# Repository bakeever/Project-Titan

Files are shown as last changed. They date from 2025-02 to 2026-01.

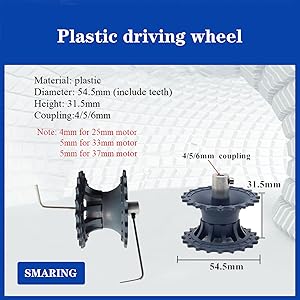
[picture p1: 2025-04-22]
Website/images/drivewheel_spec.jpg

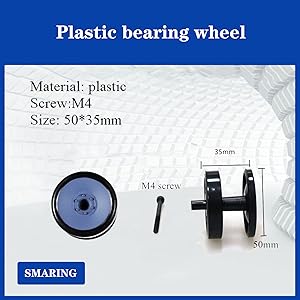
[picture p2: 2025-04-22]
Website/images/bearing_spec.jpg

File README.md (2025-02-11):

# Project TITAN - Configurations Hyperion & Theia

**Developed by Bryce Keever and Benjamin Costello**  
ENGR 385 - Integration 2 | Spring 2025  
Colorado Mesa University  

## Overview

Project TITAN is an advanced autonomous rover designed and developed to demonstrate integrated engineering concepts, including mechatronics, software development, and system integration. This project is part of the ENGR 385 - Integration 2 course at Colorado Mesa University. It serves as a comprehensive exploration of practical engineering applications, combining modern hardware, software, and design methodologies to create a fully functional autonomous system.

Each rover utilizes two Arduino MEGA microcontrollers:
- **Rover Control Unit:** Manages autonomous navigation, sensor integration, and decision-making.
- **Handheld Control Console:** Provides manual control and telemetry monitoring capabilities.

### Features
- **Arduino Programming:** Custom code for sensor input, motor control, and communication protocols.
- **Mechanical Design:** A SolidWorks assembly for the rover chassis and components.
- **Human Interface:** A handheld console for monitoring and operation, including live sensor data visualization.
- **Obstacle Detection:** Utilizes HC-SR04 ultrasonic distance sensors for obstacle detection and avoidance.
- **Precise Movement:** Driven by precision-controlled motors.
- **Control Console:** An intuitive handheld device for manual operation and telemetry feedback.

By leveraging a multidisciplinary approach, Project TITAN demonstrates the practical integration of hardware design, embedded systems, and control strategies, providing a scalable foundation for future autonomous systems research and development.

## Bill of Materials - Hyperion (Tank Rover)
| **Component** | **Description** | **Quantity** |
|---|---|---|
| Arduino MEGA | Microcontroller for the rover brain | 1 |
| Arduino MEGA | Microcontroller for the handheld control console | 1 |
| Wiring Kit | Wiring for connections | Various |
| HC-SR04 Ultrasonic Sensors | Ultrasonic distance sensors for obstacle detection | 3 |
| Motors | Motors for rover movement | TBD |
| Power Supply | 5V DC battery pack | 1 |
| Chassis Components | Mechanical parts for rover structure | TBD |
| Wheels/Tracks | Mobility components | TBD |
| Miscellaneous | Other components and accessories | TBD |

## Bill of Materials - Theia (4x4 Rover)
| **Component** | **Description** | **Quantity** |
|---|---|---|
| Arduino MEGA | Microcontroller for the rover brain | 1 |
| Arduino MEGA | Microcontroller for the handheld control console | 1 |
| Wiring Kit | Wiring for connections | Various |
| HC-SR04 Ultrasonic Sensors | Ultrasonic distance sensors for obstacle detection | 3 |
| Motors | Motors for rover movement | TBD |
| Power Supply | 5V DC battery pack | 1 |
| Chassis Components | Mechanical parts for rover structure | TBD |
| Wheels/Tracks | Mobility components | TBD |
| Miscellaneous | Other components and accessories | TBD |

## Website Link
https://org.coloradomesa.edu/~bakeever/

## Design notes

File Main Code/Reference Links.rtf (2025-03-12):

Website Links:
[Ultrasonic Sensor]
https://macduino.blogspot.com/2013/11/hc-sr04-using-multiple-ultrasonic.html#google_vignetteUBX GPS Arduino Libraryhttps://github.com/loginov-rocks/UbxGpsInstructables: Arduino Ublox GPShttps://www.instructables.com/Arduino-Ublox-GPS/SparkFun_u-blox_GNSS_Arduino_Library:https://github.com/sparkfun/SparkFun_u-blox_GNSS_Arduino_Library/tree/main

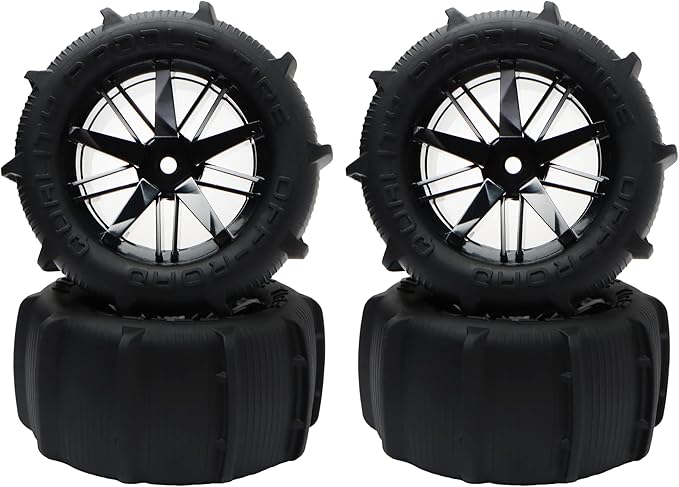
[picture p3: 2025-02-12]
Website/images/concept_rover_wheel_model.jpg

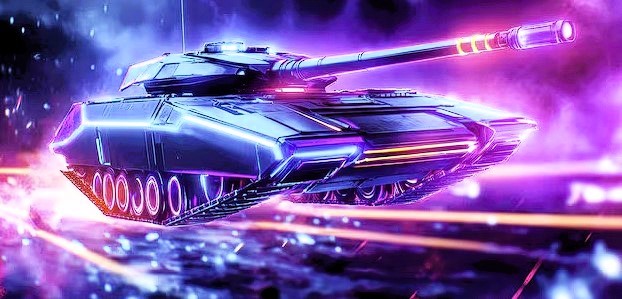
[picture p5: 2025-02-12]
Website/images/concept_drivetrain.jpg

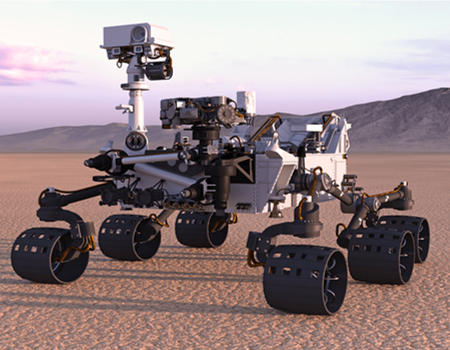
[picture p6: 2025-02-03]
Website/images/concept_rover.png

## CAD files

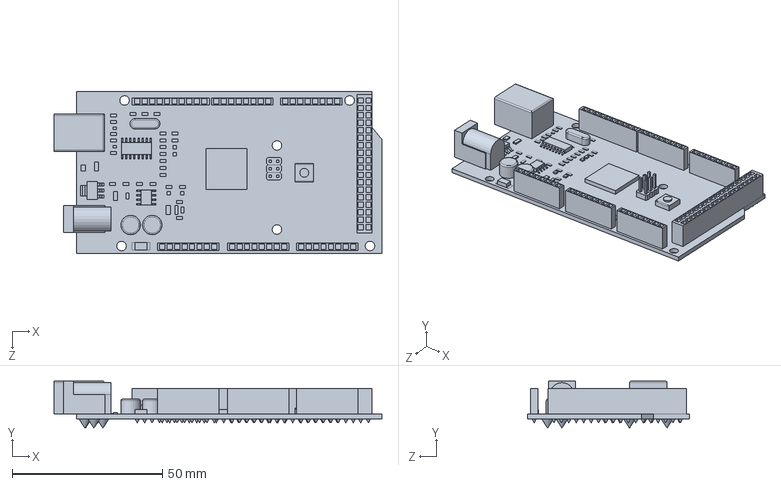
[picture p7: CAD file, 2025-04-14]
CAD/arduino-mega-18.snapshot.5/Arduino_Mega.SLDPRT
109.3 x 15.6 x 54.0 mm

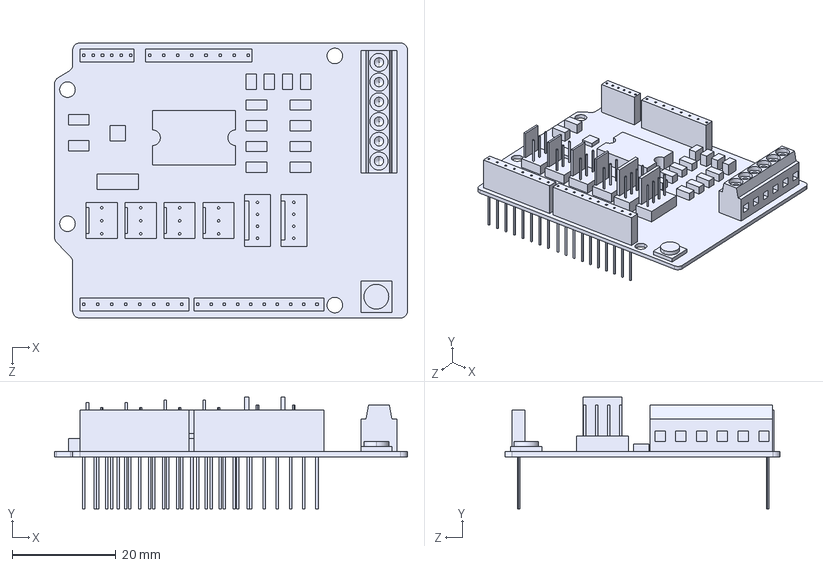
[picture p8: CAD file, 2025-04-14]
CAD/aruino-motor-shield-1.snapshot.2/arduino motor shield.STEP
68.0 x 21.5 x 53.0 mm

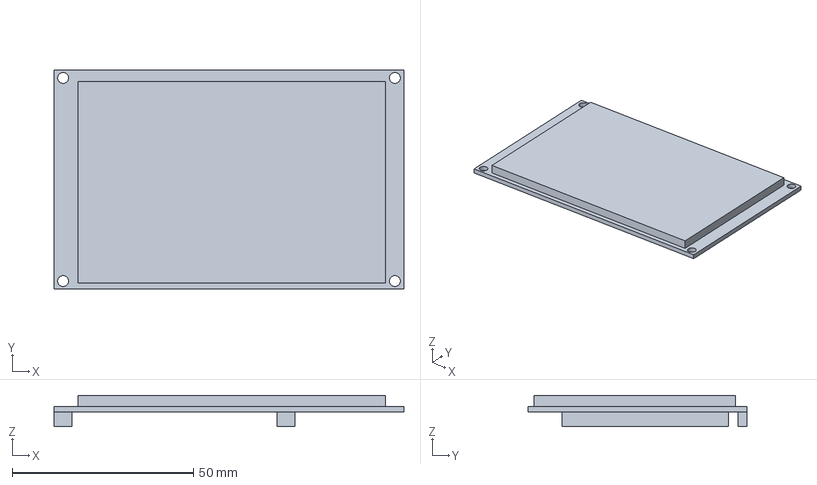
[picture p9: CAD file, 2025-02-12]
CAD/FreeCAD/Console/Screen.FCStd
96.5 x 60.3 x 8.59 mm

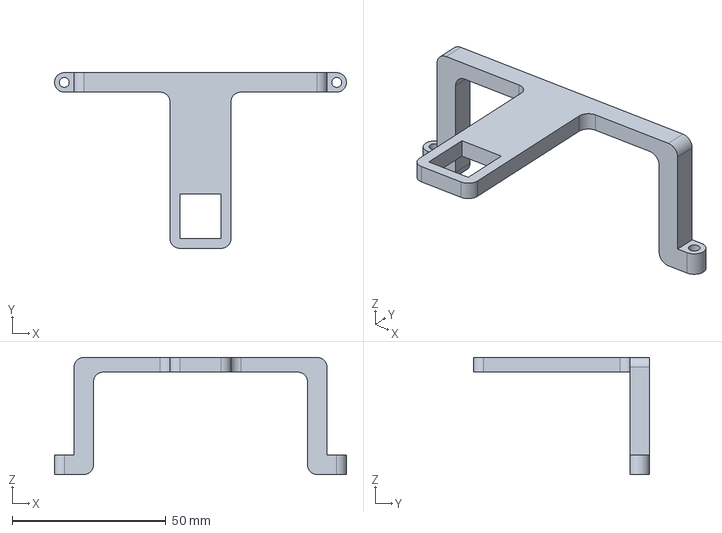
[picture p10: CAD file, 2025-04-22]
CAD/FreeCAD/Magnometer Bracket.FCStd
95.0 x 57.2 x 38.1 mm

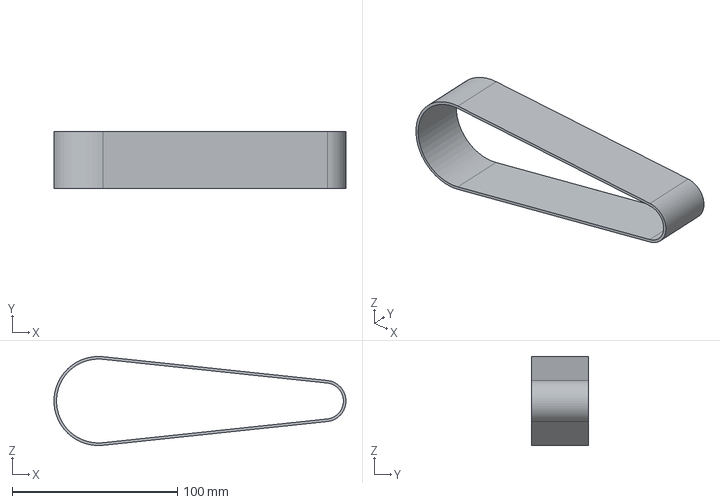
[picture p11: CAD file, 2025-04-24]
CAD/SolidWorks/Freecad Migration/Project Titan_Treadstep.step
176.9 x 34.5 x 54.0 mm

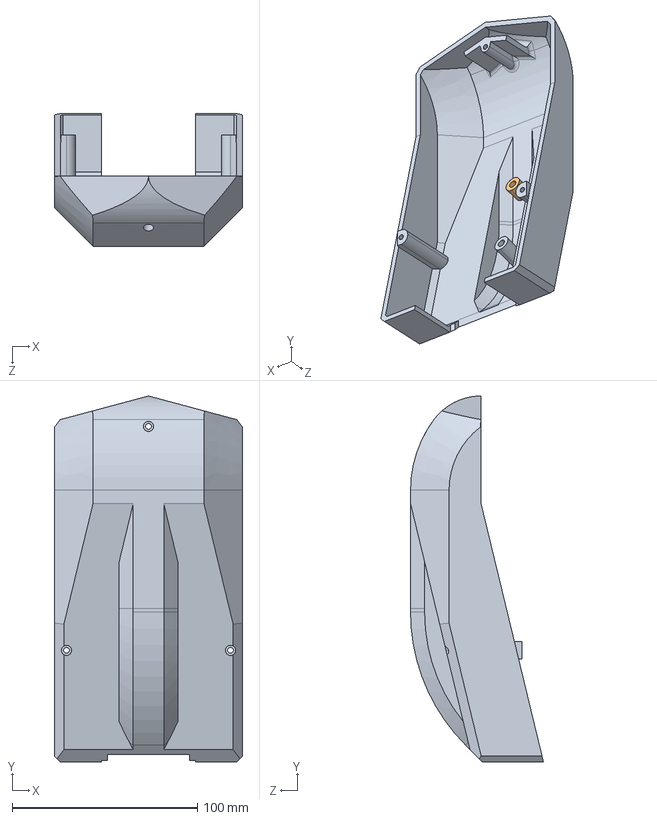
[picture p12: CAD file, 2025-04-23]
CAD/STPs/Project Titan_Chassis_Top.STEP
101.6 x 197.8 x 71.9 mm

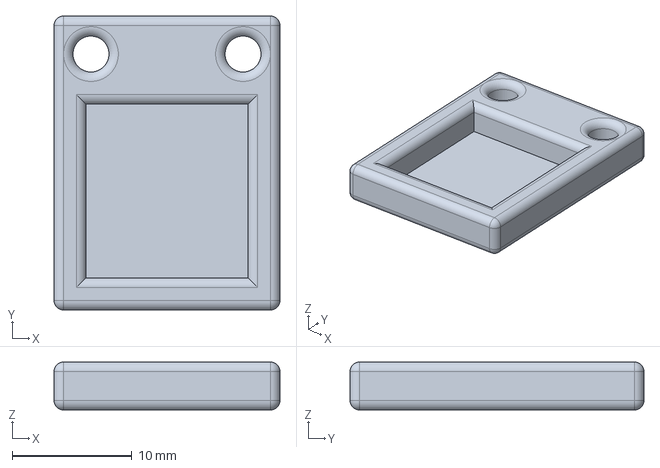
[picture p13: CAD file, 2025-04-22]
CAD/FreeCAD/Cradle_HW-246.FCStd
18.9 x 24.5 x 4.00 mm

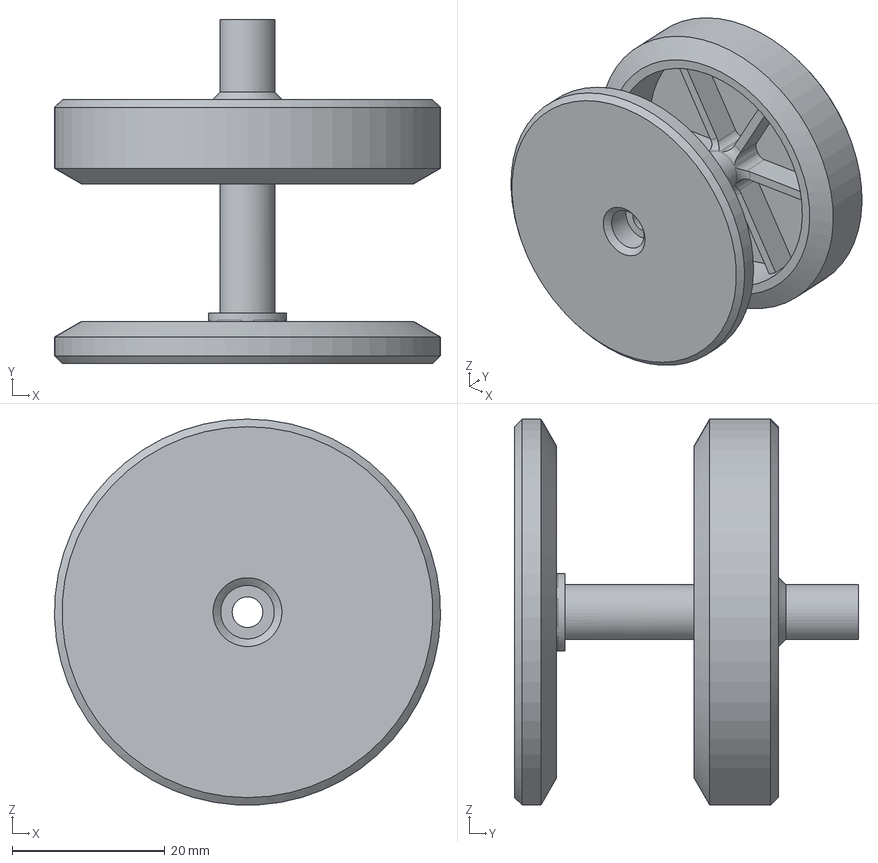
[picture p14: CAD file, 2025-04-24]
CAD/SolidWorks/Freecad Migration/Project Titan_Drive Wheel.step
50.5 x 45.0 x 50.5 mm

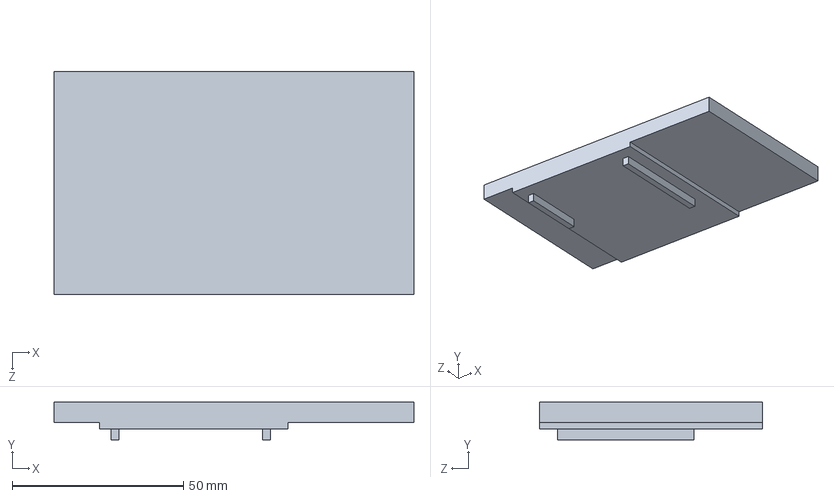
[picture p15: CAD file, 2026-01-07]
Gameduino Screen.SLDPRT
105.0 x 11.0 x 65.0 mm

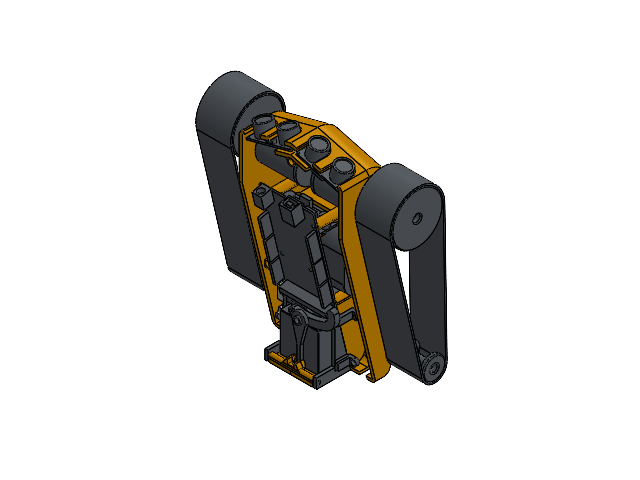
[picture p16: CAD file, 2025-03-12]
Website/downloads/Hyperion_Assembly.SLDASM
Threaded Insert_M3x4mm.step x 12
Lower Chassis.step
Tread Motor.step x 2
Tread.step x 2
Body.step
Body-0.step x 2
Body-1.step
Marker Cube.step
Body-2.step x 2
Wheels_Treads_Idler.step x 2
M3x40mm.step
M4x60mm.step
Tensioner.step
Rail Bracket_01.step x 2
Rail Bracket_01-3.step
Buck Converter.step
Buck Mount.step
Body-4.step
CAM Linkage.step
Tensioner_Rail.step x 2
Gate Linkage.step
Cube Door.step
Door Hinge.step

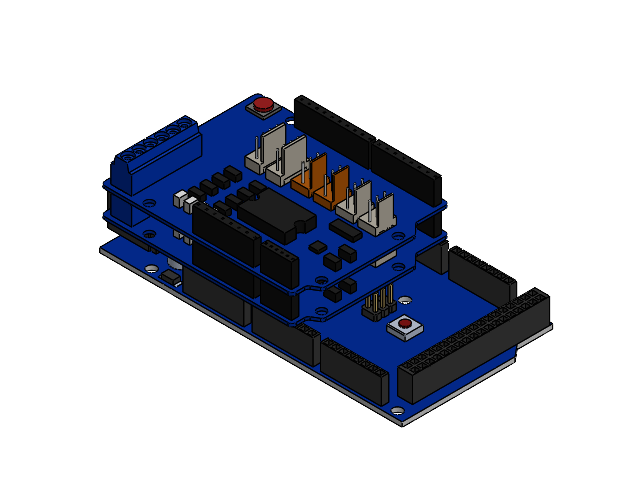
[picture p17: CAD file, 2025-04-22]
CAD/SolidWorks/Freecad Migration/Project Titan_Controller Stack.SLDASM
Arduino_Mega
arduino motor shield x 2

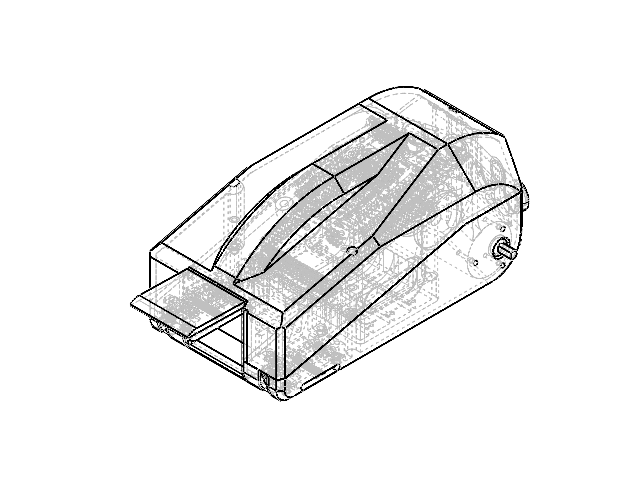
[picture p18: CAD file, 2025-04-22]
CAD/SolidWorks/Freecad Migration/Project Titan_Chassis Lower.SLDASM
Project Titan_Chassis_Base.step
Threaded Insert_M3x4mm.step x 15
Project Titan_Chassis_Compartment.step
Project Titan_Belt Tensioner_End Bracket.step x 4
Project Titan_Belt Tensioner_Linear Rail x 4
Project Titan_Belt Tensioner_Carriage.step x 2
Project Titan_Belt Tensioner_Facade.step x 2
Body.step
Project Titan_Chassis_Door.step
Project Titan_Payload Servo.step
Project Titan_Payload Arm.step
Project Titan_Ultrasonic Sensors x 2
Project Titan_Drivetrain_Motor x 2
Arduino_Mega
arduino motor shield x 2
Project Titan_Chassis_Top

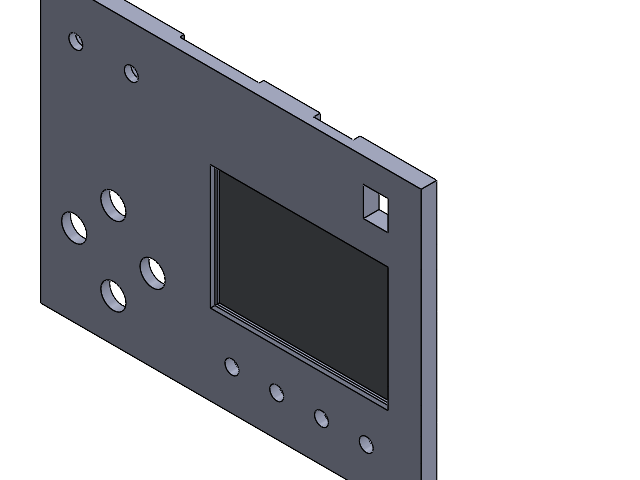
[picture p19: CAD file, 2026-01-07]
Full Assembly.SLDASM
Face Plate - Redesign v.1
Screen-Screen.step

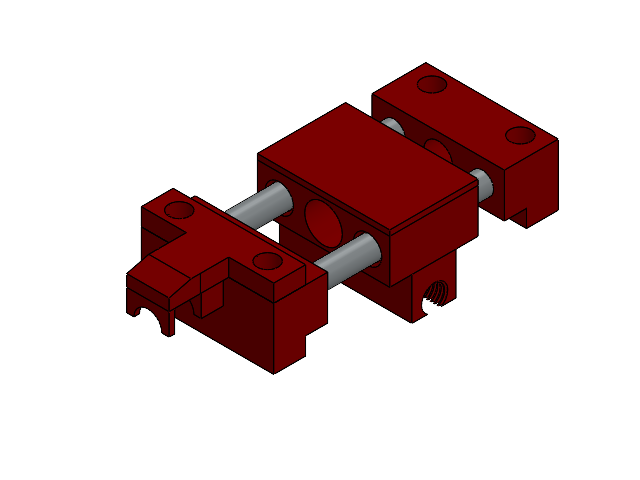
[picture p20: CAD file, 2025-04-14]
CAD/SolidWorks/Freecad Migration/Project TItan_Belt Tensioner_2025-04-14.SLDASM
Project Titan_Belt Tensioner_End Bracket.step x 2
Project Titan_Belt Tensioner_Linear Rail x 2
Project Titan_Belt Tensioner_Carriage.step
Project Titan_Belt Tensioner_Facade.step

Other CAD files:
CAD/FreeCAD/Assembly_Beta_02.FCStd
CAD/FreeCAD/Assembly_Beta_01.FCStd
CAD/FreeCAD/Console/STPs/Screen-Screen.step
CAD/STPs/Magnometer Bracket-Body.step
Arduino_Mega.SLDPRT
CAD/Blender/Draw1.SLDDRW
CAD/FreeCAD/Arduino Mega.FCStd
CAD/FreeCAD/Ball Linkage.FCStd
CAD/FreeCAD/Battery.FCStd
CAD/FreeCAD/Buck Converter.FCStd
CAD/FreeCAD/Buck Mount.FCStd
CAD/FreeCAD/CAM Linkage.FCStd
CAD/FreeCAD/Chassis Base.FCStd
CAD/FreeCAD/Chassis_01.FCStd
CAD/FreeCAD/Chassis_02.FCStd
CAD/FreeCAD/Chassis_03.FCStd
CAD/FreeCAD/Cube Door.FCStd
CAD/FreeCAD/Door Hinge.FCStd
CAD/FreeCAD/Door Hinge_Left.FCStd
CAD/FreeCAD/GPS.FCStd
CAD/FreeCAD/Gate Linkage.FCStd
CAD/FreeCAD/M3x40mm.FCStd
CAD/FreeCAD/M4x60mm.FCStd
CAD/FreeCAD/Marker Cube.FCStd
CAD/FreeCAD/Motor Shield.FCStd
CAD/FreeCAD/Motor_Treads.FCStd
CAD/FreeCAD/Rail Bracket 01.FCStd
CAD/FreeCAD/Rail Bracket 02.FCStd
CAD/FreeCAD/Sensor_ADXL345.FCStd
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

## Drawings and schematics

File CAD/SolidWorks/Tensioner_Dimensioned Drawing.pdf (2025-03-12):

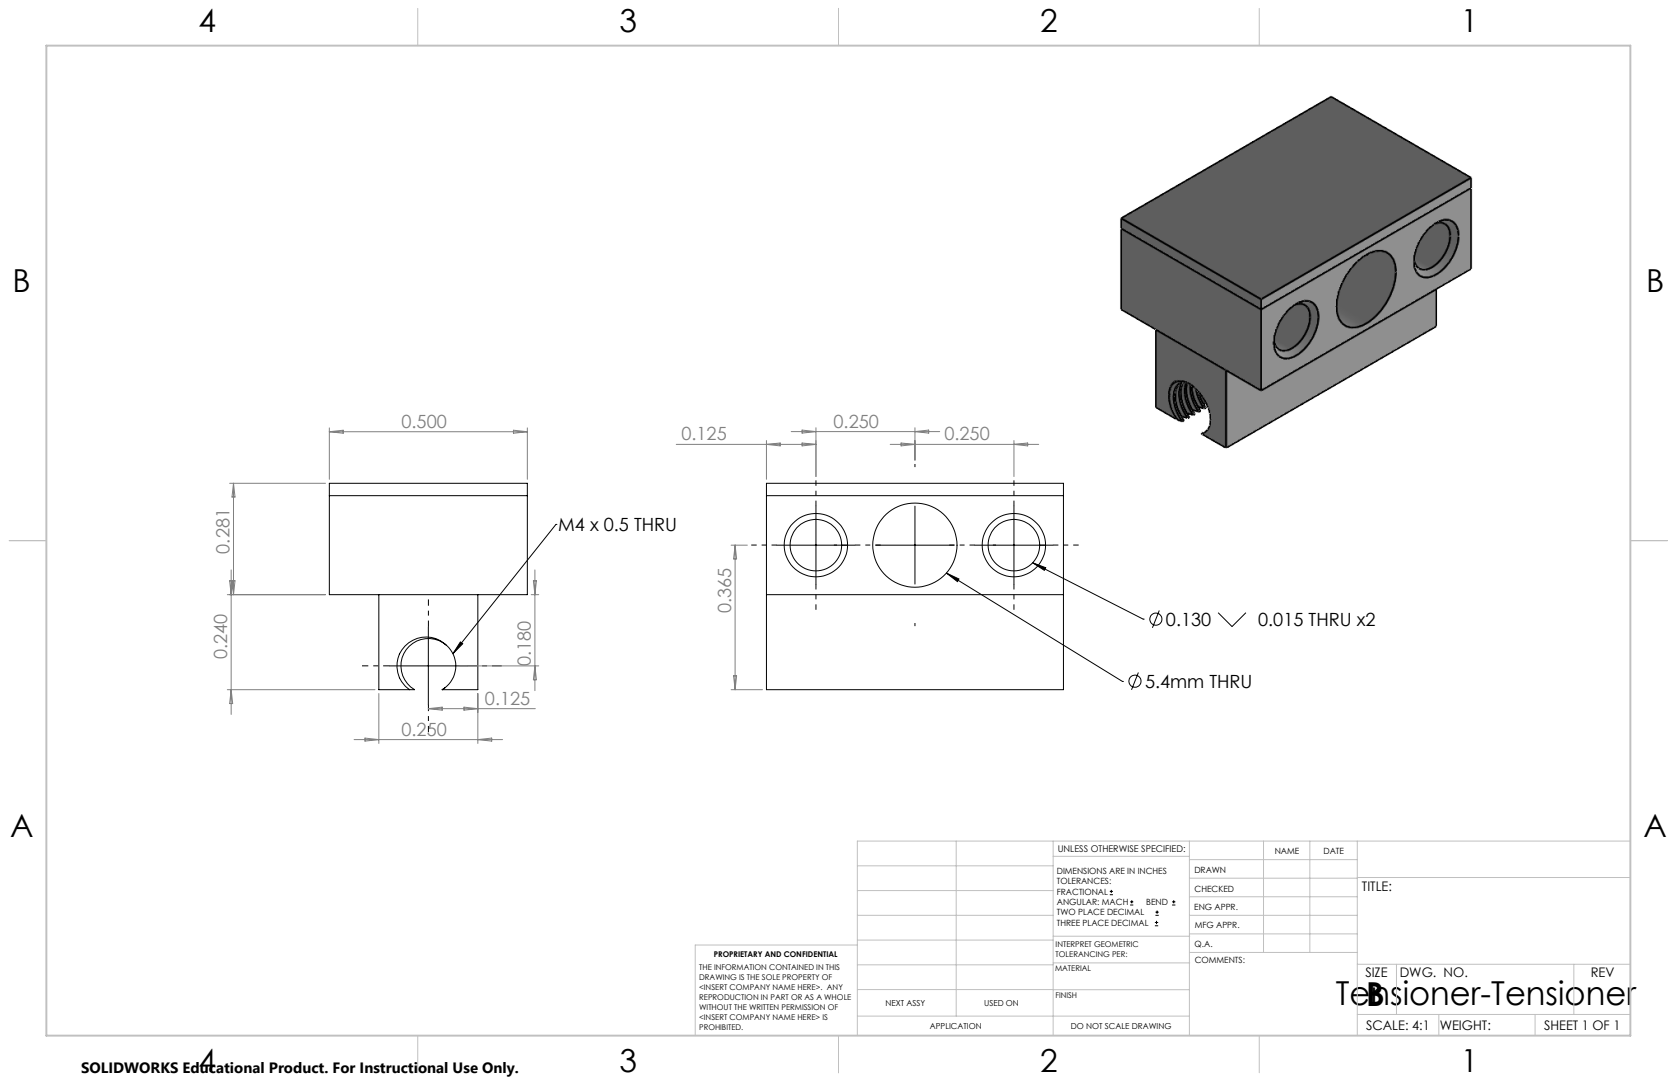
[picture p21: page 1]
M4 x 0.5 THRU; 5.4mm THRU; 0.015 THRU x2

UNLESS OTHERWISE SPECIFIED: | | NAME | DATE
DIMENSIONS ARE IN INCHES TOLERANCES: FRACTIONAL ANGULAR: MACH BEND TWO PLACE DECIMAL THREE PLACE DECIMAL | DRAWN

CHECKED | | | TITLE:

ENG APPR.
MFG APPR.

INTERPRET GEOMETRIC TOLERANCING PER: | Q.A.
MATERIAL | | SIZE B | DWG. NO. | REV

PROPRIETARY AND CONFIDENTIAL
THE INFORMATION CONTAINED IN THIS
DRAWING IS THE SOLE PROPERTY OF
<INSERT COMPANY NAME HERE>. ANY
REPRODUCTION IN PART OR AS A WHOLE
WITHOUT THE WRITTEN PERMISSION OF
<INSERT COMPANY NAME HERE> IS
PROHIBITED.

NEXT ASSY | USED ON | FINISH

APPLICATION | DO NOT SCALE DRAWING | | SCALE: 4:1 | WEIGHT: | SHEET 1 OF 1

SOLIDWORKS Educational Product. For Instructional Use Only.

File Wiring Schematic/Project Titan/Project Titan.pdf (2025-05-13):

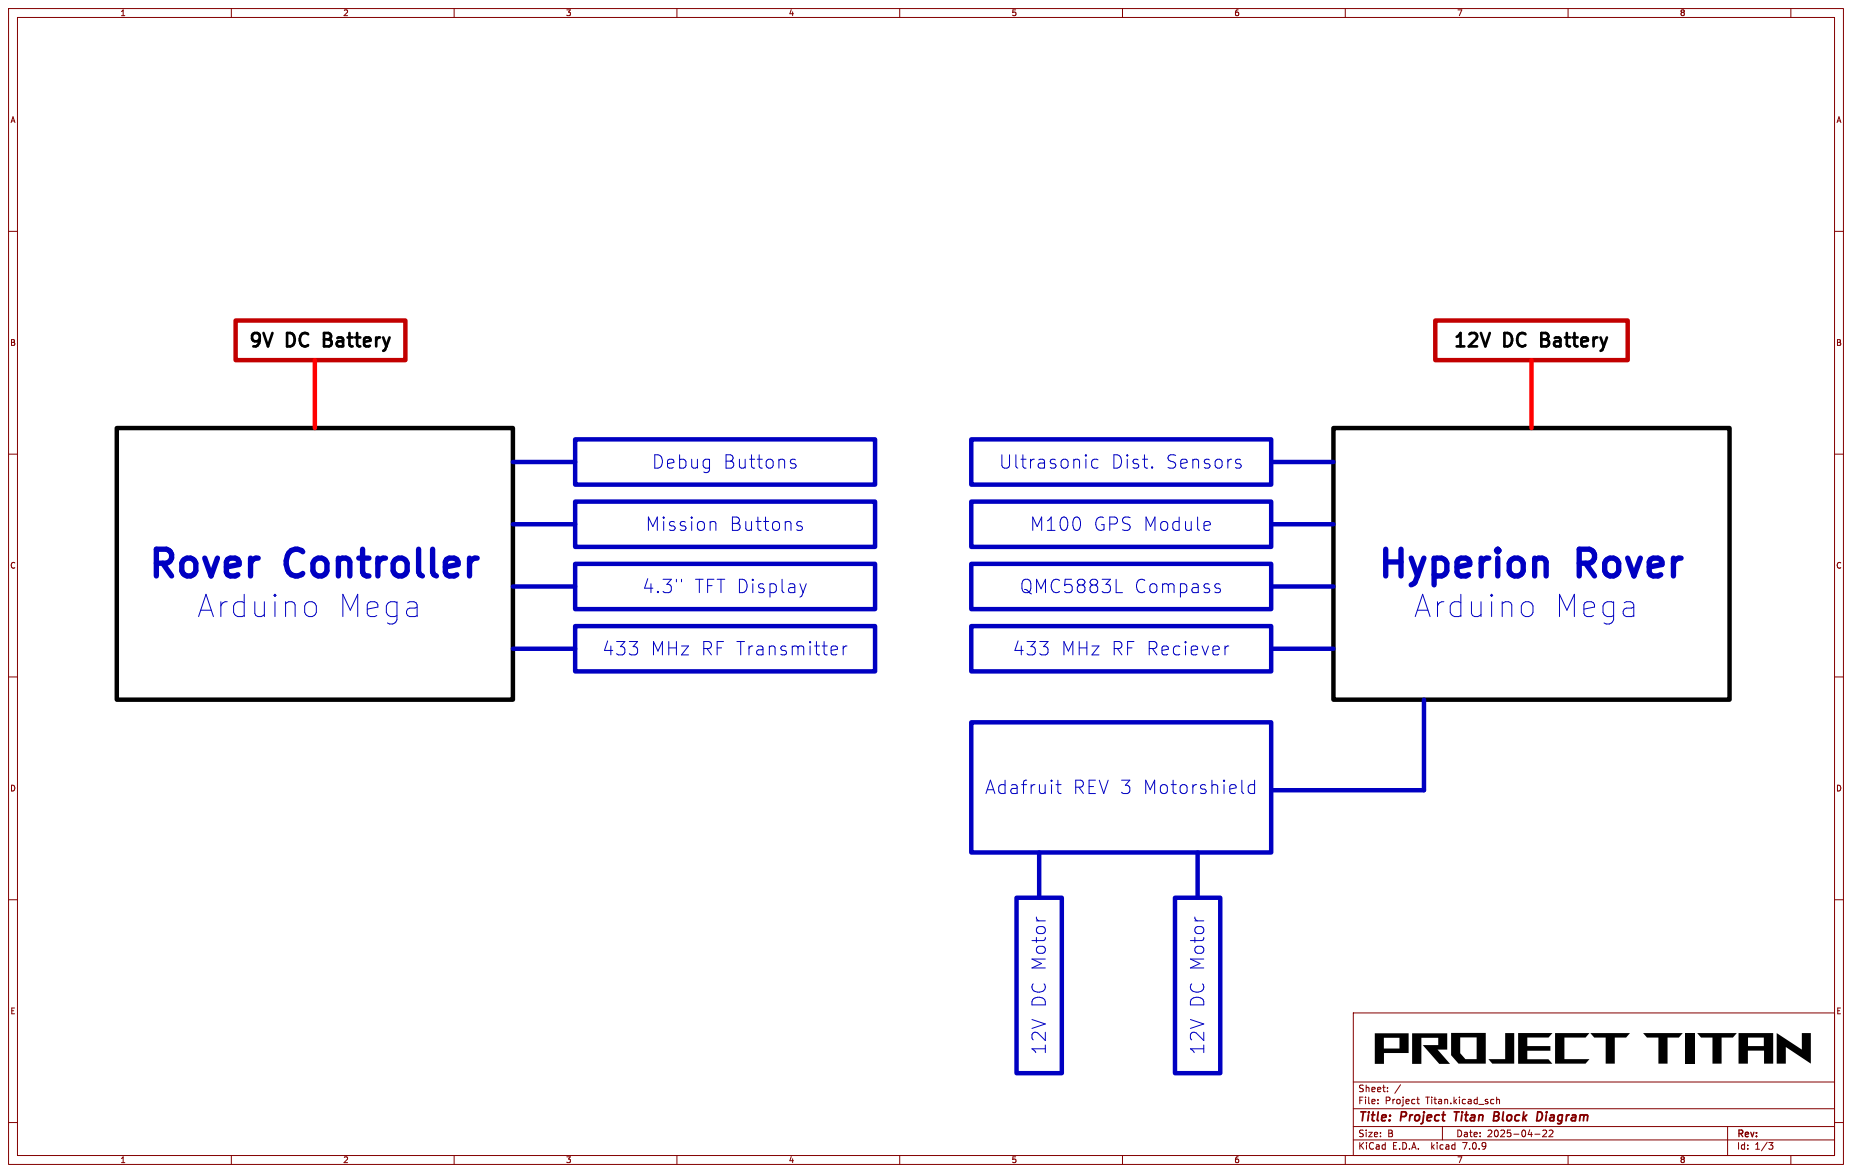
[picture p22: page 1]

Id: 1/3 Title: Project Titan Block Diagram

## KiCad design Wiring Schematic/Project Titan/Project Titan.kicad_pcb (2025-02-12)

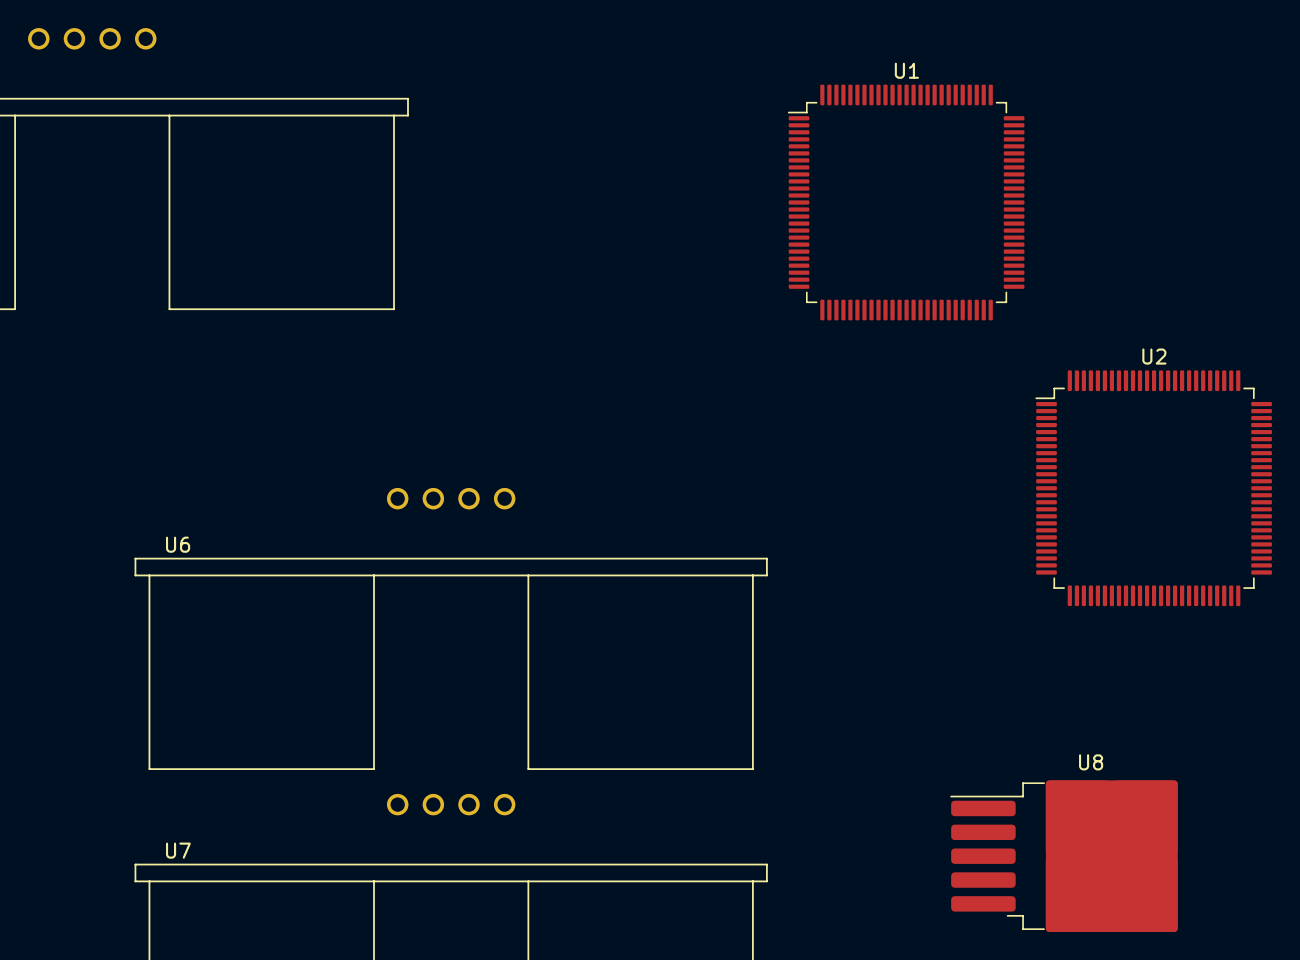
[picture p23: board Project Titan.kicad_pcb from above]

Board: 2 copper layers, 6 parts (0 on the bottom side), 4 nets, no tracks yet.

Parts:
U1, U2: ATmega2560-16A; TQFP-100_14x14mm_P0.5mm
U3, U6, U7: HC-SR04; XCVR_HC-SR04
U8: LM2596S-ADJ; TO-263-5_TabPin3

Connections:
unnamed: U1.11 (GND), U1.32 (GND), U1.62 (GND), U1.81 (GND), U1.99 (GND)
unnamed: U1.10 (VCC), U1.31 (VCC), U1.61 (VCC), U1.80 (VCC)
unnamed: U2.11 (GND), U2.32 (GND), U2.62 (GND), U2.81 (GND), U2.99 (GND)
unnamed: U2.10 (VCC), U2.31 (VCC), U2.61 (VCC), U2.80 (VCC)

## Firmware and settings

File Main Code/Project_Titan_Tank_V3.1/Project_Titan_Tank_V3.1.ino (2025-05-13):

/*
 * ==========================================================
 * Project Name: Project Titan Hyperion
 * Author: Bryce Keever
 * Date: April 9, 2025
 * Version: 3.0
 * Description: Using Arduino Motor Shield Rev3 Clone
 * ==========================================================
 */

// ==========================================================
//                      Library Includes
// ==========================================================
#include <AFMotor.h>
#include <SPI.h>
// Include RadioHead Amplitude Shift Keying Library
#include <RH_ASK.h>
#include <Servo.h>  // Include the Servo library
// I2C Library
#include <Wire.h>
// QMC5883L Compass Library
#include <QMC5883LCompass.h>
#include <TinyGPS++.h>
// ==========================================================
//                      Program Variables
// ==========================================================
// === Serial and GPS Settings ===
#define GPS_SERIAL Serial3
#define GPS_BAUD 38400
#define PC_BAUD 115200

// === Ultrasonic Variables ===
#define NUM_SAMPLES 5  // Number of readings to average
#define PULSE_TIMEOUT 30000  // Timeout for pulseIn() in microseconds
bool sensorsEnabled = true;  // Boolean flag to enable or disable sensors
const long sensorInterval = 1000;  // 1-second interval

unsigned long previousMillis = 0;
const long interval = 3000; // 3 seconds

int pos = 0; // Initial position for servo

uint16_t tread_right = 250; // Initial speed for 
uint16_t tread_left = 250;
uint8_t i; // For accel and deccel
// === RF Messaging ===
static uint8_t buf[10] = {0};  
uint8_t buflen = sizeof(buf);
char currentCommand[10] = "STOP"; // Initial state is STOP
bool turning = false;
int startHeading = 0;
int targetHeading = 0;

// ==========================================================
//                      Pin Declaration
// ==========================================================
/* Ultrasonic Sensor Pins */
#define TRIG_PIN_LEFT 22  // Pin connected to the Trig pin of the sensor
#define ECHO_PIN_LEFT 23 // Pin connected to the Echo pin of the sensor
#define TRIG_PIN_RIGHT 24  // Pin connected to the Trig pin of the sensor
#define ECHO_PIN_RIGHT 25 // Pin connected to the Echo pin of the sensor
#define STARTUP_ERROR 28
#define MAIN_ERROR 29

/* Motor Hat Pins */
const int directionPinR = 12; // Direction Pins
const int directionPinL = 13;

const int pwmPinR = 3; // PWM Pins
const int pwmPinL = 11;

const int brakePinR = 9; // Brake Pins
const int brakePinL = 8;

const bool directionState; //boolean to switch direction (not currently used)

// ==========================================================
//                   Object Declaration
// ========================================================== 

/* Create ASK objects for RF Communication */
RH_ASK rf_driver(2000,19,18,10); // Reciever [Pin 18]
RH_ASK rf_driver1(2000,18,19,10,true); // Transmitter [Pin 19]

/* Servo object */
Servo myServo; 
/* Compass Object */
QMC5883LCompass compass;
/* GPS Object */
TinyGPSPlus gps;
// ==========================================================
//               Program Function Initialization
// ==========================================================



void checkDist(){/* Ultrasonic Sensor Check */
  long duration, dist_mm, distL, distR;

  // Trigger the ultrasonic sensor
  digitalWrite(TRIG_PIN_LEFT, LOW);
  delayMicroseconds(2);
  digitalWrite(TRIG_PIN_LEFT, HIGH);
  delayMicroseconds(10);
  digitalWrite(TRIG_PIN_LEFT, LOW);

  // Measure the echo time
  duration = pulseIn(ECHO_PIN_LEFT, HIGH);

  // Convert time to distance
  distL = (duration * 0.34) / 2;  // Distance in mm

  // Resetting duration variable for reuse
  duration = 0;
  // Trigger the ultrasonic sensor
  digitalWrite(TRIG_PIN_RIGHT, LOW);
  delayMicroseconds(2);
  digitalWrite(TRIG_PIN_RIGHT, HIGH);
  delayMicroseconds(10);
  digitalWrite(TRIG_PIN_RIGHT, LOW);

  distR = (duration * 0.34) / 2;

}
/* 
* Function to return bearing from compass as int.
*/
int getBearing(){
  // Trigger a reading from the compass sensor
  compass.read();

  // Get the raw azimuth value from the compass (0 to 359 degrees)
  int rawBearing = compass.getAzimuth();

  // Apply calibration offset to correct for compass mounting/orientation error
  // Offset = 293° (factory calibration error) + 45° (custom adjustment)
  const int calibrationOffset = 338;
  int adjustedBearing = (rawBearing + calibrationOffset) % 360;
  
  //Adjust for values over 360
  if(adjustedBearing>360){adjustedBearing=adjustedBearing-360;}
  if(adjustedBearing<0){adjustedBearing = adjustedBearing+360;}
  return 360-adjustedBearing;
}
/*
* Function to return measured distance as long int.
*/
long getDistance(int trigPin, int echoPin) {
    long totalDistance, duration, distance;
    int validReadings = 0;

    digitalWrite(trigPin, LOW);
    delayMicroseconds(2);
    digitalWrite(trigPin, HIGH);
    delayMicroseconds(10);
    digitalWrite(trigPin, LOW);

    duration = pulseIn(echoPin, HIGH, PULSE_TIMEOUT);

    distance = (duration * 0.34) / 2;
    return distance;
}
void setDutyRight(int duty){
  analogWrite(pwmPinR,duty);
}
void setDutyLeft(int duty){
  analogWrite(pwmPinL,duty);
}
// Function: Sets Rover Direction Forward
void setDirFor(){
  digitalWrite(directionPinR, HIGH); 
  digitalWrite(directionPinL, LOW);  
}
// Function: Sets Rover Direction backward_debugs
void setDirBack(){
  digitalWrite(directionPinR, LOW); 
  digitalWrite(directionPinL, HIGH);  
}
// Function: Sets Rover Direction Right
void setDirRight(){
  digitalWrite(directionPinR, LOW); 
  digitalWrite(directionPinL, LOW);  
}
// Function: Sets Rover Direction Left
void setDirLeft(){
  digitalWrite(directionPinR, HIGH); 
  digitalWrite(directionPinL, HIGH);  
}

/*
* Function: Sets rover brakes based on passed input (T/F).
*/
void setBrakes(bool state){
  if(state == true){
    //activate brakes
    digitalWrite(brakePinR, HIGH);
    digitalWrite(brakePinL, HIGH);
  }
  else if(state == false){
    //deactivate brakes
    digitalWrite(brakePinR, LOW);
    digitalWrite(brakePinL, LOW);
  }
}
// void accel() {
//   static int i = 0;
//   static unsigned long lastUpdate = 0;

//   if (i < 255 && millis() - lastUpdate > 250) { // Slower acceleration
//     // setDutyRight(i);
//     // setDutyLeft(i);
//     i += 0.1;  // Change to i += 2 for a faster increase
//     lastUpdate = millis();
//   }
// }
// void decel(){
//   static int i = 255;
//   static unsigned long lastUpdate = 0;
  
//   if (i > 0 && millis() - lastUpdate > 5) {
//     // setDutyRight(i);
//     // setDutyLeft(i);
//     i--;
//     lastUpdate = millis();
//   }
// }

/*
* Function to command rover to move forward for hardcoded time delay.
*/
void forward_debug(){
    Serial.print("Forward debug");

    // Set Direction Forward
    digitalWrite(12, LOW); //Establishes forward direction of Channel A
    digitalWrite(13, HIGH);  //Establishes forward direction of Channel B

    // 
    digitalWrite(9, LOW);   //Disengage the Brake for Channel A
    digitalWrite(8, LOW);   //Disengage the Brake for Channel B

    int tread = 255;
    analogWrite(3, tread);   //Spins the motor on Channel A at full speed
    analogWrite(11, tread);    //Spins the motor on Channel B at full speed

    delay(1000);

    digitalWrite(9, HIGH);  //Engage the Brake for Channel A
    digitalWrite(8, HIGH);  //Engage the Brake for Channel B

    analogWrite(3, 0);  
    analogWrite(11, 0);   

}
/*
* Function to command rover to move forward for given time delay.
* Also includes straight line adjustment based on heading value.
*/
void forward(int wait){
    int ForwardHeading = getBearing();
    int startTime = millis();
    Serial.print("Forward debug");
    // Set Direction Forward
    digitalWrite(12, HIGH); //Establishes forward direction of Channel A
    digitalWrite(13, LOW);  //Establishes backward_debug direction of Channel B

    // Disengagese Brakes
    digitalWrite(9, LOW);   //Disengage the Brake for Channel A
    digitalWrite(8, LOW);   //Disengage the Brake for Channel B
  
    analogWrite(3, 255);   //Spins the motor on Channel A at full speed
    analogWrite(11, 255);    //Spins the motor on Channel B at half speed

    if (getBearing() < ForwardHeading){
        tread_right = tread_right - 5;
        // setDutyRight(tread_right);
        analogWrite(3, tread_right);   // Changes the speed of Channel A
        tread_left = tread_left +5;
        // setDutyLeft(tread_left);
        analogWrite(11, tread_left);    // Changes the speed of Channel B
    }
    else if (getBearing() > ForwardHeading){
        tread_right = tread_right + 5;
        // setDutyRight(tread_right);
        analogWrite(3, tread_right);   // Changes the speed of Channel A
        tread_left = tread_left - 5;
        // setDutyLeft(tread_left);
        analogWrite(11, tread_left);    // Changes the speed of Channel B
    }
    if (millis() > startTime + wait){
      digitalWrite(9, HIGH);  //Engage the Brake for Channel A
      digitalWrite(8, HIGH);  //Engage the Brake for Channel B
    }
}
/*
* Function to command rover to move forward for given delay time and num of loops.
*/
void forward(int wait, int loops){
  /*
    New version of "forward" function, modifying by controlling each motor 
    on sinusodal pattern to cause the rover to drive in a wobbly
    fashion, thus increasing the chance of seeing a wall before 
    running into it.
  */
  int i = 0; // Variable for number of loops
  float angle = 0; //this angle is in RADIANS
  // setDirFor();
  // setBrakes(false); //release breaks
  // setDutyRight(255);
  // setDutyLeft(255);

  // Set Direction Forward
  digitalWrite(12, HIGH); //Establishes forward direction of Channel A
  digitalWrite(13, LOW);  //Establishes backward_debug direction of Channel B
  // Disengagese Brakes
  digitalWrite(9, LOW);   //Disengage the Brake for Channel A
  digitalWrite(8, LOW);   //Disengage the Brake for Channel B

  while (i<loops){
    float tread_right = (sin(angle+3.14159)+1)*255;
    float tread_left = (sin(angle)+1)*255;
    Serial.print("Forward debug");
    // setDutyRight(tread_right);
    // setDutyLeft(tread_left);
    analogWrite(3, tread_right);   // Changes the speed of Channel A
    analogWrite(11, tread_left);    // Changes the speed of Channel B
    delay(wait);

    angle = angle + 3.14159;
    i++;
  }
  //activate breaks
  // setBrakes(true);
  // //set work duty for the motor to 0 (off)
  // setDutyRight(0);
  // setDutyLeft(0);
  digitalWrite(9, HIGH);  //Engage the Brake for Channel A
  digitalWrite(8, HIGH);  //Engage the Brake for Channel B
}
/*
* Mission Function: Move rover forward.
*/
void Forward(){
    // Set Direction Forward
    digitalWrite(12, LOW); //Establishes forward direction of Channel A
    digitalWrite(13, HIGH);  //Establishes forward direction of Channel B

    // 
    digitalWrite(9, LOW);   //Disengage the Brake for Channel A
    digitalWrite(8, LOW);   //Disengage the Brake for Channel B

    int tread = 255;
    analogWrite(3, tread);   //Spins the motor on Channel A at full speed
    analogWrite(11, tread);    //Spins the motor on Channel B at full speed
    delay(1000);
}
/*
* Function to command rover to move backward for hardcoded time delay.
*/
void backward_debug(){
    Serial.print("backward debug");

    // Set Direction Forward
    digitalWrite(12, HIGH); //Establishes forward direction of Channel A
    digitalWrite(13, LOW);  //Establishes forward direction of Channel B

    // 
    digitalWrite(9, LOW);   //Disengage the Brake for Channel A
    digitalWrite(8, LOW);   //Disengage the Brake for Channel B

    int tread = 255;
    analogWrite(3, tread);   //Spins the motor on Channel A at full speed
    analogWrite(11, tread);    //Spins the motor on Channel B at full speed

    delay(1000);

    digitalWrite(9, HIGH);  //Engage the Brake for Channel A
    digitalWrite(8, HIGH);  //Engage the Brake for Channel B

    analogWrite(3, 0);  
    analogWrite(11, 0);  
}
/*
* Mission Function: Move rover backward.
*/
void Backward(){

}
/*
* Function to command rover to turn to the right 90 degrees.
*/
void right(){
    Serial.println("RIGHT TURN");
      //Motor A forward @ full speed
    digitalWrite(12, LOW); //Establishes forward direction of Channel A
    digitalWrite(9, LOW);   //Disengage the Brake for Channel A
    analogWrite(3, 255);   //Spins the motor on Channel A at full speed

    //Motor B backward_debug @ half speed
    digitalWrite(13, LOW);  //Establishes backward_debug direction of Channel B
    digitalWrite(8, LOW);   //Disengage the Brake for Channel B
    analogWrite(11, 255);    //Spins the motor on Channel B at half speed

    delay(150);

    digitalWrite(9, HIGH);  //Engage the Brake for Channel A
    digitalWrite(8, HIGH);  //Engage the Brake for Channel B

    analogWrite(3, 0);  
    analogWrite(11, 0);  
    // setDirRight();        // Set motors to turn right (left motor forward, right motor backward_debug)
    // setBrakes(false);     // Release brakes
    // setDutyRight(200);    // Power for right motor (backward_debug)
    // setDutyLeft(200);     // Power for left motor (forward)
    // delay(300);           // Duration of the turn
    // setBrakes(true);      // Apply brakes
    // setDutyRight(0);      // Stop motors
    // setDutyLeft(0);
}
/*
* Function to command rover to turn to the right 90 degrees.
* Includes heading value to turn right with increaed accuracy.
*/
void right3(){
    Serial.println("RIGHT TURN");

    int ForwardHeading = getBearing(); // Store the current heading
    digitalWrite(12, LOW); //Establishes forward direction of Channel A
    digitalWrite(13, LOW);
  

    // Set Duty of both motors
    analogWrite(3, 255);  
    analogWrite(11, 255);    
    // Turn until heading is approx. 90° less than starting heading
    while (getBearing() > ForwardHeading - 90){
        Serial.print("turning");
        delay(5);
    }
    digitalWrite(9, HIGH);  //Engage the Brake for Channel A
    digitalWrite(8, HIGH);  //Engage the Brake for Channel B

    setDutyRight(0);
    setDutyLeft(0);
}
/*
* Function to command rover to turn to the left 90 degrees.
*/
void left(){
    Serial.println("LEFT TURN");
    //Motor A forward @ full speed
    digitalWrite(12, HIGH); //Establishes forward direction of Channel A
    digitalWrite(9, LOW);   //Disengage the Brake for Channel A
    analogWrite(3, 255);   //Spins the motor on Channel A at full speed

    //Motor B backward_debug @ half speed
    digitalWrite(13, HIGH);  //Establishes backward_debug direction of Channel B
    digitalWrite(8, LOW);   //Disengage the Brake for Channel B
    analogWrite(11, 255);    //Spins the motor on Channel B at half speed

    delay(150);

    digitalWrite(9, HIGH);  //Engage the Brake for Channel A
    digitalWrite(8, HIGH);  //Engage the Brake for Channel B

    analogWrite(3, 0);  
    analogWrite(11, 0);  
    // setDirLeft();         // Set motors to turn left (right motor forward, left motor backward_debug)
    // setBrakes(false);     // Release brakes
    // setDutyRight(200);    // Power for right motor (forward)
    // setDutyLeft(200);     // Power for left motor (backward_debug)
    // delay(300);           // Duration of the turn
    // setBrakes(true);      // Apply brakes
    // setDutyRight(0);      // Stop motors
    // setDutyLeft(0);
}
/*
* Function: Left turn until rover has rotated approximately 90 degrees.
* Includes heading value to turn right with increaed accuracy.
*/
void left3(){
    Serial.println("LEFT TURN");

    int ForwardHeading = getBearing(); // Store the current heading
    setDirLeft();                      // Set motors for left turn (right forward, left backward_debug)
    setBrakes(false);                 // Release brakes

    setDutyRight(200);                // Power both motors
    setDutyLeft(200);

    // Turn until heading
    while (getBearing() < ForwardHeading + 90){
        Serial.print("turning");
        delay(5);
    }
    setBrakes(true);                 // Stop the rover
    setDutyRight(0);
    setDutyLeft(0);
}
/*
* Payload Function: Moves swing arm with servo to ejecto the payload.
*/
void payload(){
  int pos = 0;    // variable to store the servo position
  for (pos = 180; pos >= 0; pos -= 1) { // goes from 180 degrees to 0 degrees
    myServo.write(pos);              // tell servo to go to position in variable 'pos'
    delay(2);                       // waits 15ms for the servo to reach the position
  }
    for (pos = 0; pos <= 180; pos += 1) { // goes from 0 degrees to 180 degrees in steps of 1 degree
    myServo.write(pos);              // tell servo to go to position in variable 'pos'
    delay(5);                       // waits 15ms for the servo to reach the position
  }
}
/*
* Function to return distance. Used in previous missions to calculate distance per time.
*/
void travelDistance(int distance){
  // Given that 10 feet takes 4000ms, calculate delay as 400ms per foot - changed to 4.77/ft
  int delayTime = distance * 380;
  Serial.print("Traveling ");
  Serial.print(distance);
  Serial.print(" feet (");
  Serial.print(delayTime);
  Serial.println(" ms).");
  forward(delayTime);
  delay(1000);
  payload();
  delay(500);
  forward(500);
}
/*
* Handshake Function: Verifies RF communication is working.
*/
bool handshakeRF(){
  if (rf_driver.recv(buf, &buflen)) {
    buf[buflen] = '\0';  // Null-terminate the received message
    Serial.print("Received: ");
    Serial.println((char*)buf);

    // If handshake message received, respond with "ACK"
    if (strcmp((char*)buf, "HANDSHAKE") == 0) {
        Serial.println("Sending ACK...");
        char ackMsg[] = "ACK";
        rf_driver1.send((uint8_t *)ackMsg, strlen(ackMsg));
        rf_driver1.waitPacketSent();
        return true;
    }
  }
}
/* 
* Handshake function: Verifies functionality of both motors, direction setting and brakes. 
*/
bool handshakeMotor(){
  // Set Direction Forward
  digitalWrite(12, HIGH); //Establishes forward direction of Channel A
  digitalWrite(13, LOW);  //Establishes backward_debug direction of Channel B
  //release breaks
  digitalWrite(brakePinR, LOW);
  digitalWrite(brakePinL, LOW);
  //set work duty for the motor
  analogWrite(pwmPinR, 255);
  analogWrite(pwmPinL, 255);
  delay(500);
  //activate breaks
  digitalWrite(brakePinR, HIGH);
  digitalWrite(brakePinL, HIGH);
  // Set Direction backward_debug
  digitalWrite(12, HIGH); //Establishes forward direction of Channel A
  digitalWrite(13, LOW);  //Establishes backward_debug direction of Channel B
  //set work duty for the motor
  analogWrite(pwmPinR, 255);
  analogWrite(pwmPinL, 255);
  delay(500);
  //activate breaks
  digitalWrite(brakePinR, HIGH);
  digitalWrite(brakePinL, HIGH);
  //set work duty for the motor to 0 (off)
  analogWrite(pwmPinR, 0);
  analogWrite(pwmPinL, 0);
  delay(1000);
  return true;
}
/* 
* Handshake function: Verifies functionality of GPS and GPS-Compass.
*/

/* 
* Handshake function: Verifies functionality of both Ultrasonic distance sensors.
*/
bool handshakeUltra(){
  long duration, distL, distR;

  // Trigger the ultrasonic sensor
  digitalWrite(TRIG_PIN_LEFT, LOW);
  delayMicroseconds(2);
  digitalWrite(TRIG_PIN_LEFT, HIGH);
  delayMicroseconds(10);
  digitalWrite(TRIG_PIN_LEFT, LOW);

  // Measure the echo time
  duration = pulseIn(ECHO_PIN_LEFT, HIGH);

  // Added delay for reading accuracy
  delay(100);
  
  // Convert time to distance
  distL = (duration * 0.34) / 2;  // Distance in mm
  // Trigger the ultrasonic sensor
  digitalWrite(TRIG_PIN_RIGHT, LOW);
  delayMicroseconds(2);
  digitalWrite(TRIG_PIN_RIGHT, HIGH);
  delayMicroseconds(10);
  digitalWrite(TRIG_PIN_RIGHT, LOW);
  // Measure the echo time
  duration = pulseIn(ECHO_PIN_RIGHT, HIGH);
  distR = (duration * 0.343) / 2;
  Serial.print("Distance Left:"); Serial.println(distL);
  Serial.print("Distance Right:"); Serial.println(distR);
  return true;
}
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
void loop() {
  if (rf_driver.recv(buf, &buflen)) {
      buf[buflen] = '\0';  // Null-terminate the received message
      Serial.print("Received: ");
      Serial.println((char*)buf);
      // Process movement commands
      parseCommand((char*)buf);
      Serial.print("Waiting for next command");
      memset(buf, 0, sizeof(buf));
      delay(50);  // Small delay to prevent CPU overload
  }
  // Continuously execute movement based on latest command
  executeMovement();
}

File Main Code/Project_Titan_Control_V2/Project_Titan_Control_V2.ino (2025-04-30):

/*
 * ==========================================================
 * Project Name: Project Titan Control Center
 * Author: Bryce Keever
 * Date: January 27, 2025
 * Version: 2.0 - Modular Mission Handler
 * Description: Modular mission logic using TFT_HX8357 and RH_ASK
 * ==========================================================
 */

// ==========================================================
//                      Library Includes
// ==========================================================
#include <TFT_HX8357.h>
#include <SPI.h>
#include <RH_ASK.h>

// ==========================================================
//                      Object Declaration
// ==========================================================
TFT_HX8357 tft = TFT_HX8357();
RH_ASK rf_driver(2000, 19, 18, 10);  // TX on D18, RX on D18
bool wasManualAdjustActive = false;
int activeManualAdjust = -1; // Index in missions[], or -1 if none active
// ==========================================================
//                      Mission Struct
// ==========================================================
struct Mission {
  int pin;
  bool state;
  int prevState;
  const char* name;
  const char* onMessage;
  const char* offMessage;
  bool isManualAdjust;
  int potIndex;
};


// ==========================================================
//                      Mission Array
// ==========================================================
Mission missions[] = {
  {11, false, HIGH, "Mission 1A", "Scouting Perimeter", "Stop Mission 1A", false, -1},
  {10, false, HIGH, "Mission 1B", "Kamikaze Assignment", "Stop Mission 1B", false, -1},
  {9,  false, HIGH, "Mission 2A", "Analyzing Minerals", "Stop Mission 2A", false, -1},
  {8,  false, HIGH, "Mission 4A",  "I'm going on an adventure!", "Stop Mission 3", false, -1},

  {14, false, HIGH, "Adjust1", "Manual Adjust 1 Enabled", "Manual Adjust 1 Disabled", true, 0},
  {15, false, HIGH, "Adjust2", "Manual Adjust 2 Enabled", "Manual Adjust 2 Disabled", true, 1},
  {A9, false, HIGH, "Adjust3", "Manual Adjust 3 Enabled", "Manual Adjust 3 Disabled", true, 2},
  {A8, false, HIGH, "Adjust4", "Manual Adjust 4 Enabled", "Manual Adjust 4 Disabled", true, 3}
};




const int NUM_MISSIONS = sizeof(missions) / sizeof(missions[0]);

// ==========================================================
//                      Pin Declaration
// ==========================================================
const int button7 = 7;  // Move Backward
const int button6 = 6;  // Move Left
const int button5 = 5;  // Move Right
const int button4 = 4;  // Move Forward
const int button3 = 3;  // E-STOP

// Manual Adjustment Buttons
const int button14 = 14;  // Set Manual Adjust 1
const int button15 = 15;  // Set Manual Adjust 2

const int potPin_1 = A0;
const int potPin_2 = A1;
const int potPin_3 = A2;
const int potPin_4 = A3;
// ==========================================================
//                      Variables
// ==========================================================
String activeMission = "None";
String missionData = "Awaiting Data";

// ==========================================================
//                      Setup
// ==========================================================
void setup() {
  Serial.begin(115200);
  tft.begin();
  tft.setRotation(1);

  if (!rf_driver.init()) {
    Serial.println("RF Module Initialization Failed!");
  } else {
    Serial.println("RF Module Initialized.");
  }

  // E-STOP
  pinMode(button3, INPUT_PULLUP);
  attachInterrupt(digitalPinToInterrupt(button3), toggleLoop, FALLING);

  splash();

  // Button Pins
  for (int i = 4; i <= 11; i++) {
    pinMode(i, INPUT_PULLUP);
  }
  for (int i = 14; i <= 17; i++) {
    pinMode(i, INPUT_PULLUP);
  }
    for (int i = A4; i <= A9; i++) {
    pinMode(i, INPUT_PULLUP);
  }
}


// ==========================================================
//                      Splash Screen
// ==========================================================
void splash() {
  tft.fillScreen(TFT_BLACK);
  tft.setTextColor(TFT_WHITE, TFT_BLACK);
  tft.setTextSize(3);
  int16_t x = 65;  // original centering
  tft.setCursor(x, 140);
  tft.print("Project Titan");
  tft.setTextSize(2);
  tft.setCursor(x, 170);  // 30 pixels below
  tft.print("Tiny Frame. Boundless Vision.");
  delay(3000);

  tft.fillScreen(TFT_BLACK);
  tft.setTextSize(2);
  tft.setCursor((480 - (25 * 2 * 7)) / 2, 10); // Centered title
  tft.print("Project Titan Control Center");

  int boxX = 10, boxY = 70, boxWidth = 460, boxHeight = 240;
  tft.drawRect(boxX, boxY, boxWidth, boxHeight, TFT_WHITE);
  tft.setCursor(boxX + 10, boxY + 10);
  tft.print("Mission Data:");
  tft.setCursor(boxX + 10, boxY + 30);
  tft.print(missionData);
}

// ==========================================================
//                      Mission Display
// ==========================================================
void updateActiveMission(String mission) {
  if (mission != activeMission) {
    activeMission = mission;
    String activeMissionText = "Active Mission: " + activeMission;
    int16_t mission_width = activeMissionText.length() * 12; // Assume 12px/char
    int16_t mission_x_center = (480 - mission_width) / 2;

    tft.setTextSize(2);
    tft.setTextColor(TFT_WHITE, TFT_BLACK);
    tft.fillRect(0, 35, 480, 24, TFT_BLACK); // clear line at y=35
    tft.setCursor(mission_x_center, 35);
    tft.print(activeMissionText);
  }
}


void updateMissionData(String data) {
  if (data != missionData) {
    missionData = data;
    tft.setTextSize(2);
    tft.setTextColor(TFT_WHITE, TFT_BLACK);
    tft.fillRect(20, 100, 440, 200, TFT_BLACK);
    tft.setCursor(20, 100);
    tft.print(missionData);
  }
}


// ==========================================================
//                      Mission Handling
// ==========================================================
void handleMissions() {
  for (int i = 0; i < NUM_MISSIONS; i++) {
    bool current = digitalRead(missions[i].pin);
    if (current == LOW && missions[i].prevState == HIGH) {
      missions[i].state = !missions[i].state;
      updateActiveMission(missions[i].name);
      updateMissionData(missions[i].state ? missions[i].onMessage : "Idle");
      sendCommand(missions[i].state ? missions[i].name : missions[i].offMessage);
    }
    missions[i].prevState = current;
  }
}

// ==========================================================
//                      Movement Controls
// ==========================================================
void moveForward() {
  sendCommand("FORW");
  Serial.println("Jog Forward");
}
void moveBackward() {
  sendCommand("BACK");
  Serial.println("Jog Backward");
}
void turnLeft() {
  sendCommand("LEFT");
  Serial.println("Jog Left");
}
void turnRight() {
  sendCommand("RIGH");
  Serial.println("Jog Right");
}
// ==========================================================
//                      Adjustment Controls
// ==========================================================
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

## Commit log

2025-02-03 Update
    Should be all basic framework for website. Just needs to be populated with images and documents.
2025-02-04 Added CAD directory
    [Arduino Mega.FCStd, Assembly_Beta_01.FCStd, Chassis_01.FCStd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]
2025-02-04 CAD update
    -Enlarged Idler shaft diameter to allow for free rotation on shaft.
    -added Servo, battery
    [Battery.FCStd, GPS.FCStd, Servo.FCStd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]
2025-02-04 End of evening push
    [Arduino Mega.FCStd, Assembly_Beta_01.FCStd, Chassis_01.FCStd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]
2025-02-05 Updated chassis. Assembly is left broken
    [Arduino Mega.FCStd, Assembly_Beta_01.FCStd, Battery.FCStd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]
2025-02-05 Wiring Structure Update
2025-02-05 Floating Assembly with all major components. Shows what Hyperion could look like
    [Assembly_Beta_01.FCStd, Sensor_Radio.FCStd, Wheels_Treads_Idler.FCStd]
2025-02-05 No real changes
    [Arduino Mega.FCStd, Assembly_Beta_01.FCStd, Battery.FCStd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]
2025-02-07 Frame 1 update
    [Arduino Mega.FCStd, Assembly_Beta_01.FCStd, Chassis_01.FCStd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]
2025-02-08 Beta assembly with STPs
    [Assembly_Beta_01.FCStd, Beta Parts Print.3mf, Chassis_01-Right Tread Panel.3mf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]
2025-02-10 Wiring Update
    [Project Titan.kicad_pcb, Project Titan.kicad_sch]
2025-02-11 New Chassis
    [Assembly_Beta_02.FCStd, Chassis Base.FCStd, Chassis_01.FCStd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]
2025-02-11 Update README.md
    Website Link Fix & Added BOM Changes
2025-02-12 Logo update
    [Assembly_Beta_02.FCStd, Chassis Base.FCStd, Sensor_Ultrasonic.FCStd]
2025-02-12 Logo fix #2
    [Assembly_Beta_02.FCStd, Chassis Base.FCStd]
2025-02-12 Added screen.stp for console
    [Screen-Screen.step, Screen.FCStd]
2025-02-12 near completion on chaassis base
    [Arduino Mega.FCStd, Assembly_Beta_02.FCStd, Battery.FCStd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]
2025-02-14 Base STP ready
    [Assembly_Beta_02.FCStd, Chassis Base-Lower Chassis.step, Chassis Base.FCStd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]
2025-02-14 Added mounting points on chassis base for the top half to be attached
    [Assembly_Beta_02.FCStd, Chassis Base-Lower Chassis.step]
2025-02-15 added first componenet of tensioner
    [Assembly_Beta_02.FCStd, M3x40mm.FCStd, M4x60mm.FCStd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]
2025-02-16 Added base for tread tensioner
    [Assembly_Beta_02.FCStd, Rail Bracket 01.FCStd, Tread Tension adjuster.FCStd]
2025-02-17 Tensioner almost ready
    [Assembly_Beta_02.FCStd, Rail Bracket 01.FCStd, Rail Bracket 02.FCStd]
2025-02-18 Rails are designed and exported as stps
    [Assembly_Beta_02.FCStd, Rail Bracket 01-Rail Bracket_01.step, Rail Bracket 01.FCStd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]
2025-02-23 Buck booster mount STP added
    [Assembly_Beta_02.FCStd, Buck Converter.FCStd, Buck Mount-Buck Mount.step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]
2025-02-24 Created First pieces for payload dropping system.
    [Assembly_Beta_02.FCStd, Ball Linkage.FCStd, CAM Linkage.FCStd]
2025-02-26 Fixed broken assembly joints
    [Assembly_Beta_02.FCStd, Tensioner_Rail.FCStd]
2025-02-28 Door Assembly 80%
    [Assembly_Beta_02.FCStd, CAM Linkage-CAM Linkage.step, CAM Linkage.FCStd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]
2025-02-28 Door Extras
    [Ball Linkage.FCStd]
2025-03-01 Block pooper V1
    [CAM Linkage-CAM Linkage.step, CAM Linkage.FCStd, Cube Door-Cube Door.step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]
2025-03-01 Minor door update
    [Assembly_Beta_02.FCStd, CAM Linkage.FCStd, Cube Door-Cube Door.step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]
2025-03-04 SolidWorks Assembly created
    [Assembly_Beta_02.SLDASM]
2025-03-04 Website Update for Grading #2
    [Hyperion_Assembly.SLDASM]
2025-03-05 Current Working Code
2025-03-05 Mission 1 succesful perameters
    - Rover changes speed after it's run for a while. the motor controllers heat up, giving extra juice. Need magnometers or encoders to verify correct feeds and speeds
    [Project_Titan_Tank.ino]
2025-03-10 Added dimensioned drawing
    [Tensioner-Tensioner.SLDDRW, Tensioner-Tensioner.SLDPRT]
2025-03-12 second chassis adjustments
    [Chassis Base-Lower Chassis.step, Wheels_Treads_Idler_small-Wheels_Treads_Idler.step]
2025-03-24 Schematic Update
    [Hyperion.kicad_sch, Project Titan.kicad_sch]
2025-03-24 Sensor models are built
    [Sensor_ADXL345.FCStd, Sensor_HW-246.FCStd, Sensor_RF sender.FCStd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]
2025-03-24 Magnometer cradle
    [Cradle_HW-246-Body.step, Cradle_HW-246.FCStd]
2025-03-24 cradle pt.2
    [Assembly_Beta_02.FCStd, Cradle_HW-246.FCStd, Sensor_HW-246.FCStd]
2025-03-24 Added sin correction to avoid negative values
    [Project_Titan_Tank.ino]
2025-03-24 exported Buck Converter
    [Buck Converter.step]
2025-03-24 Update Buck Mount-Buck Mount.step
    [Buck Mount-Buck Mount.step]
2025-03-26 Mission 2A nearly functional code
    [Buck Mount.FCStd]
2025-04-02 Fixed compass module
    cleaned up code structure, added correct compass navigation
    [Compass_Readout.ino, Project_Titan_Tank.ino]
2025-04-02 more conservative motor speed M3
2025-04-02 Fixed function bracket error
2025-04-14 Freecad -> Solidworks Migration
    [Arduino_Mega.PLY, Arduino_Mega.SLDPRT, Assembly_Beta_02.FCStd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]
2025-04-21 old changes
    [Cradle_HW-246.FCStd, Magnometer Bracket-Body.step, Magnometer Bracket.FCStd]
2025-04-22 Tank lid
    [Project Titan_Chassis Lower.SLDASM, Project Titan_Chassis_Top.SLDPRT, Project Titan_Controller Stack.SLDASM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]
2025-04-22 Update: Code Structure Revision
    Changed the motor variable declarations.
    Attempted to standardized function descriptions.
2025-04-23 CAD update
    [Project Titan_Chassis_Top.SLDPRT, Project Titan_Chassis_Top.STEP, Project Titan_Chassis_Top.STL]
2025-04-24 Full SOLIDWORKS Model for upload
    [Assembly_Beta_02.SLDASM, Project Titan_Drive Wheel.step, Project Titan_Treadstep.step]
2025-05-07 Update Project_Titan_Tank_V3.ino
    Implement Mission 4B - RF waypoint navigation and return with GPS
    - Modified `mission_42()` function to support full waypoint mission behavior
    - Parses RF-transmitted GPS waypoint in format: "N09495W58784"
    - Constructs target GPS coordinates from 12-char message
    - Waits for valid GPS fix before executing motion
    - Saves current location as start point before traveling
    - Navigates to the waypoint using `driveTowardsTarget()`
    - Deploys payload upon arrival
    - Returns to original start location using GPS
    - Brakes and halts once within 2m of each goal
    - Structured mission flow to mirror `mission_41()` for clarity and modularity
    - Added debugging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
    [Project_Titan_Tank_V3.ino]
2025-05-07 Update Project_Titan_Tank_V3.ino
    - Enhanced driveTowardsTarget() to detect and avoid obstacles using ultrasonic sensors
    - Uses TRIG_PIN_LEFT / RIGHT and ECHO_PIN_LEFT / RIGHT to measure distance
    - Performs U-turn if obstacle detected ahead (both sensors < 300mm)
    - Performs side-step (left/right) if obstacle is detected on one side
    - Reorients after avoidance and resumes GPS navigation
    - Keeps mission_41 and mission_42 logic unchanged by embedding avoidance in steering
    - Added forward detour segments after turns to ensure obstacle is cleared
    - Improves reliability of GPS missions in indoor or cluttered environments
    - Ensures rover avoids collisions without compromising pathf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
    [Project_Titan_Tank_V3.ino]
